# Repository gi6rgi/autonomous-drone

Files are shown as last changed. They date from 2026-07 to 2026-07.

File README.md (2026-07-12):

# Follow-me дрон: 5" deadcat на SpeedyBee F405 V3 + Raspberry Pi 5

Дрон, следующий за объектом: ArduPilot держит машину в воздухе, Raspberry Pi 5
видит цель через камеру и шлёт полётному контроллеру команды скорости по MAVLink
(режим GUIDED).

```
frame/frame.py        параметрическая рама (build123d -> STL/STEP)
frame/export/         готовые файлы: STL на печать, STEP для FreeCAD
software/follow/      код follow-me для Pi
software/tools/       утилиты: маркер, тест камеры, тест связи
```

---

## 1. Железо

### Что уже есть
SpeedyBee F405 V3 BLS 50A (FC+ESC), 6S 4000 mAh, моторы RETEK LN2207
(**используйте версию 1960 KV**, на первые полёты `MOT_SPIN_MAX` ~0.85),
винты 5.1x3.7x3, GPS Neo-M8M, Pi 5 + Arducam IMX219 175°, XT60, smoke stopper.

### Докупить обязательно
| Что | Зачем |
|---|---|
| Приёмник + пульт (ELRS 2.4G) | ручное управление и аварийный перехват. **Без RC не летать.** |
| BEC 5V/5A с входом 2–8S (до 35 В) | питание Pi 5. **MINI560 обычно до 20 В — на 6S сгорит, проверьте маркировку** |
| Крепёж: M3x12 (8 шт, армы) + гайки с нейлоном, стойки M3x30 (4) + M3x8 (8), M2.5x8 + стойки (Pi), M2x6 (камера), M3x8 (кронштейн/мачта) | сборка |
| Ремешок АКБ 20 мм, пенка под АКБ, стяжки | |
| Если на плате GPS нет компаса (чип QMC5883) | модуль GPS+компас — Loiter будет заметно стабильнее |

### Схема соединений
```
6S XT60 ─┬─ ESC (пады +/- , конденсатор Low-ESR прямо на пады!)
         └─ BEC 5V/5A ── Pi 5 (пины 5V: GPIO-пин 2/4 и GND 6)

FC UART (свободный, напр. T4/R4) ── Pi 5 UART: GPIO14 TXD -> RX FC,
                                    GPIO15 RXD <- TX FC, GND общий
GPS: TX/RX -> UART GPS-пады FC, SDA/SCL (компас) -> I2C пады FC
Камера IMX219 -> CSI-шлейф Pi 5 (нужен шлейф 22pin mini -> 15pin, если не в комплекте)
Приёмник ELRS -> UART2 FC (обычно пады T2/R2 + 4.5V)
```
Логика UART у FC и Pi — 3.3 В, соединяются напрямую. TX всегда крест-накрест с RX.

---

## 2. Рама

### Генерация
```bash
.venv/bin/python frame/frame.py     # -> frame/export/*.stl, *.step, assembly.step
```
Все размеры — параметры в начале `frame/frame.py` (база, толщина арма, наклон
камеры и т.д.). Поменяли — перезапустили — получили новые файлы. STEP открывается
во FreeCAD для доработки, `assembly.step` — вся рама в сборе для проверки.

### Детали и печать
| Деталь | Кол-во | Ориентация | Настройки |
|---|---|---|---|
| `arm.stl` | 4 | плашмя | PETG/ABS, **6+ периметров, заполнение 50% gyroid**, 100% для первых 2 мм |
| `bottom_plate.stl` | 1 | плашмя | 5 периметров, 40% |
| `top_plate.stl` | 1 | плашмя | 4 периметра, 30% |
| `camera_bracket.stl`, `gps_mast.stl` | 1+1 | базой вниз | обычные |

PLA не использовать (плывёт от нагрева моторов). Армы — расходник: печатайте
сразу 6 штук. Если MVP полетит стабильно — плиты и армы стоит перевести на
карбон, печатными оставить кронштейны.

### Сборка
1. Хвостовики армов вставляются в карманы снизу нижней плиты, M3x12 сверху,
   гайки с нейлоном снизу.
2. Моторы — на площадки армов (M3 из комплекта моторов), провода вдоль арма
   стяжками.
3. Стек на нижнюю плиту (30.5x30.5, люверсы), стрелка FC — вперёд (в нос).
4. Стойки M3x30 -> верхняя плита -> Pi 5 на стойках M2.5, камера в кронштейн
   на носу (наклон 10° вниз уже в детали), GPS на мачту на корме.
5. АКБ снизу на ремешке через прорези, пенка между АКБ и гайками армов.
   Двигайте АКБ вперёд/назад до баланса: центр тяжести — на оси стека.

---

## 3. Прошивка FC (ArduPilot)

1. Скачайте ArduCopter для таргета **SpeedyBeeF405v3** с firmware.ardupilot.org.
2. Первая прошивка — через DFU (зажать boot-кнопку, USB): STM32CubeProgrammer
   или Mission Planner -> Load custom firmware (`*_with_bl.hex`).
3. В Mission Planner: FRAME_CLASS=1 (Quad), FRAME_TYPE=1 (X). Deadcat-геометрию
   ArduPilot считает обычным X — для наших углов это ок.
4. Калибровки: акселерометр, компас, радио, ESC (BLHeli_S — протокол DShot300:
   `MOT_PWM_TYPE=4`).
5. Ключевые параметры:
```
SERIALx_PROTOCOL = 2      # MAVLink2 на UART, куда подключён Pi
SERIALx_BAUD     = 921    # 921600
MOT_PWM_TYPE     = 4      # DShot300
MOT_SPIN_MAX     = 0.85   # бережём моторы/ESC на 6S первое время
BATT_MONITOR     = 4      # ток+напряжение со стека
FS_THR_ENABLE    = 1      # потеря RC -> RTL
BATT_FS_LOW_ACT  = 2      # низкая батарея -> RTL
BATT_LOW_VOLT    = 21.6   # 3.6 В/банка
GUID_TIMEOUT     = 3      # нет команд от Pi 3 с в GUIDED -> зависание
```
6. Режимы на тумблеры: `Stabilize | AltHold | Loiter` + отдельный тумблер
   `RTL` и **GUIDED** (появится после настройки; GUIDED = «управляет Pi»).
7. Motor Test (без винтов!): порядок и направление по схеме ArduPilot X.

---

## 4. Raspberry Pi 5

```bash
# Raspberry Pi OS Bookworm 64-bit
sudo apt update && sudo apt install -y python3-picamera2 python3-opencv python3-pip
cd software && pip install -r requirements.txt --break-system-packages

# UART для FC: в /boot/firmware/config.txt добавить
#   enable_uart=1
#   dtparam=uart0=on
# и отключить консоль на serial: sudo raspi-config -> Interface -> Serial Port
#   (login shell: No, hardware: Yes). Порт: /dev/ttyAMA0 (GPIO14/15).
```

Камеру проверить: `rpicam-hello -t 5000` (для IMX219 обычно работает из коробки).

---

## 5. Проверка софта по шагам (до полёта)

```bash
cd software
python tools/generate_aruco.py            # напечатать маркер ~30 см, размер в config.yaml
python tools/test_camera.py               # кадр с детекцией -> frame.jpg
python tools/test_link.py                 # heartbeat, режим, батарея, GPS
python -m follow.main --dry-run           # весь конвейер без отправки команд
```

Опционально, без дрона — SITL на ПК (симулятор ArduPilot):
```bash
# https://ardupilot.org/dev/docs/sitl-simulator-software-in-the-loop.html
sim_vehicle.py -v ArduCopter --out=udp:127.0.0.1:14550
# в config.yaml: connection: udp:127.0.0.1:14550, camera.backend: opencv
# маркер показывайте в веб-камеру
```

---

## 6. Полётная программа (по порядку, не перескакивать)

1. **Стенд**: первое включение только через smoke stopper. Без винтов.
2. **Полёт 1–2**: Stabilize/AltHold, триммирование, затем AUTOTUNE (с этой
   массой стоковые PID будут вялыми).
3. **Полёт 3**: Loiter — дрон должен неподвижно стоять в точке. Пока Loiter
   не идеален, follow-me не включать.
4. **Полёт 4**: Pi запущен (`python -m follow.main`), маркер стоит на земле.
   Взлёт в Loiter, повернуть дрон камерой на маркер, тумблер -> **GUIDED**.
   Дрон должен довернуться на маркер и подойти на 4 м. Рука на тумблере:
   что-то не так -> LOITER.
5. Маркер в руках, медленная ходьба. Потом поднимать скорости в config.yaml.

**Безопасность**: открытое поле, без людей в радиусе 30 м; цель потеряна ->
Pi сам зависает через 0.5 с и уходит в LOITER через 5 с; батарея < 21 В ->
LOITER; RC-тумблер всегда главнее Pi.

## 7. Что дальше (после MVP)
- Fisheye-калибровка камеры (cv2.fisheye) — точные углы/дистанция по всему кадру.
- Трекинг человека: YOLOv8n (640x384, ~5–10 FPS на Pi 5) вместо ArUco,
  файл `follow/tracker.py` — добавить класс по образцу.
- Удержание высоты по цели (vz), follow сбоку/сзади, гео-забор в `safety.py`.

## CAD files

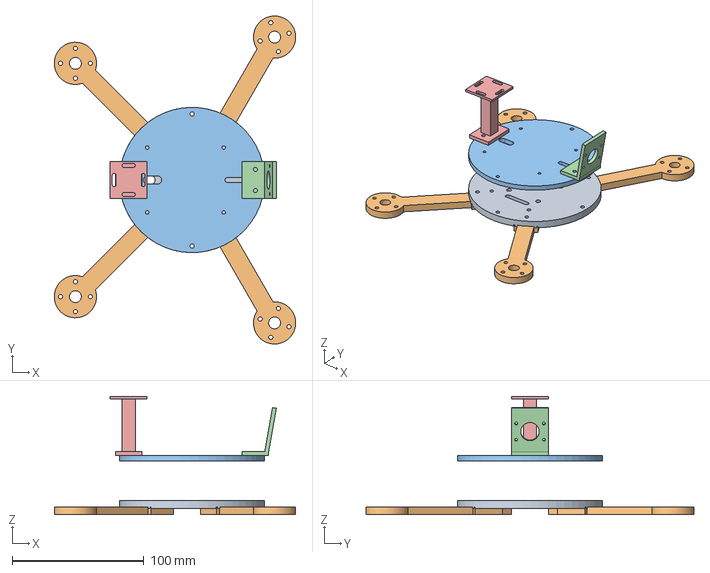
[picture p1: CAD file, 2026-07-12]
frame/export/assembly.step
182.8 x 248.5 x 89.7 mm

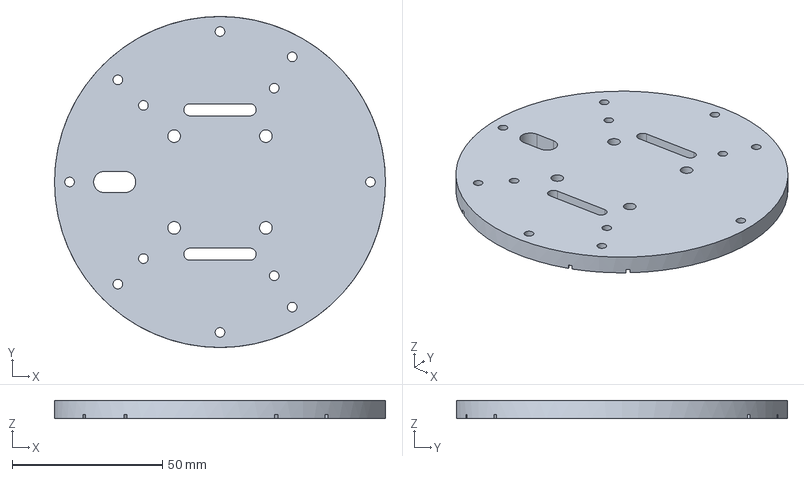
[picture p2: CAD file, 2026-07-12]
frame/export/bottom_plate.step
110.0 x 110.0 x 6.00 mm

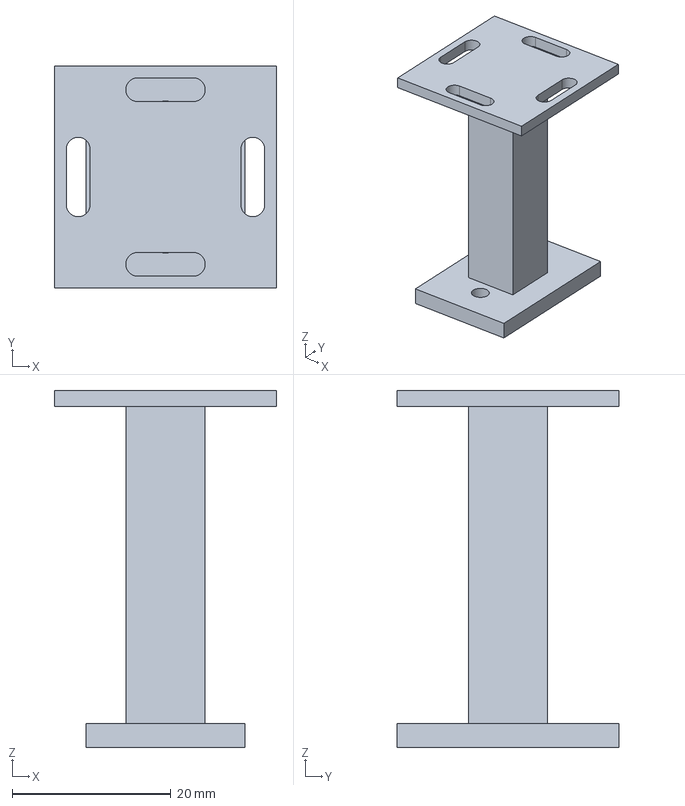
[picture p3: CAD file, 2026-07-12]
frame/export/gps_mast.step
28.0 x 28.0 x 45.0 mm

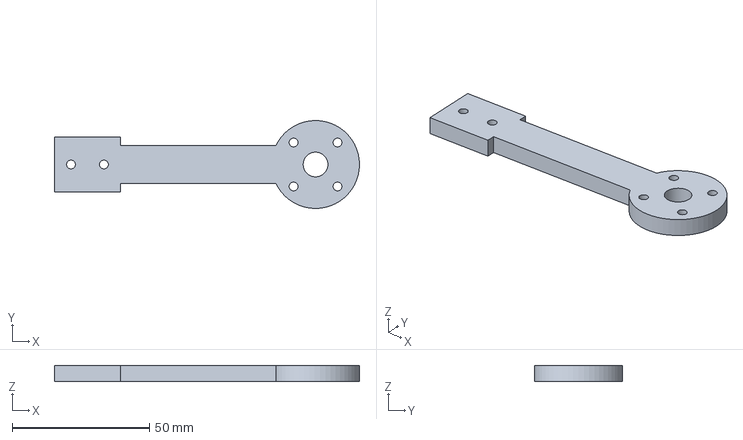
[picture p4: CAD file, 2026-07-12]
frame/export/arm.step
111.0 x 32.0 x 6.00 mm

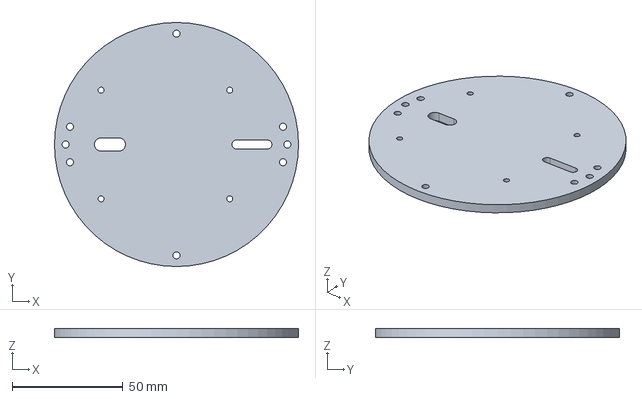
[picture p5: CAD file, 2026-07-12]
frame/export/top_plate.step
110.0 x 110.0 x 4.00 mm

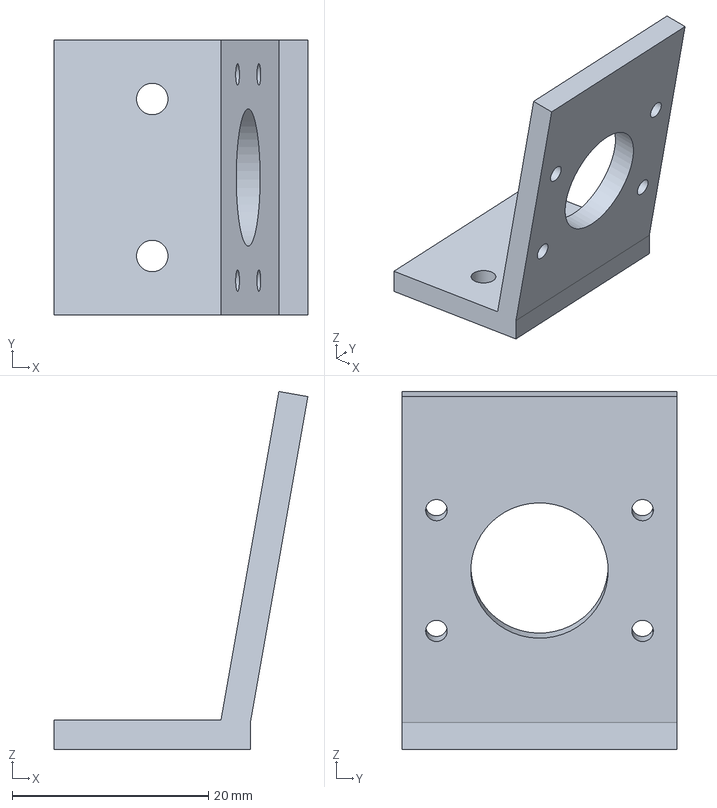
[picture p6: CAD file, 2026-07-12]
frame/export/camera_bracket.step
25.9 x 28.0 x 36.5 mm

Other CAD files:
frame/export/arm.stl
frame/export/assembly.FCStd
frame/export/bottom_plate.stl
frame/export/camera_bracket.stl
frame/export/gps_mast.stl
frame/export/top_plate.stl

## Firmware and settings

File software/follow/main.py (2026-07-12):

"""Главный цикл follow-me.

Запуск на Pi:      python -m follow.main --config config.yaml
Отладка без FC:    python -m follow.main --config config.yaml --dry-run

Логика: команды скорости отправляются ТОЛЬКО когда FC armed и в GUIDED.
Во всех остальных режимах программа лишь наблюдает и печатает телеметрию —
можно безопасно держать её запущенной с момента включения.
"""
from __future__ import annotations

import argparse
import time

import yaml

from .camera import Camera
from .controller import FollowController
from .safety import Safety, TRACK, HOVER, LOITER
from .tracker import make_tracker


def main():
    ap = argparse.ArgumentParser()
    ap.add_argument("--config", default="config.yaml")
    ap.add_argument("--dry-run", action="store_true",
                    help="без MAVLink: печатать команды вместо отправки")
    args = ap.parse_args()

    with open(args.config) as f:
        cfg = yaml.safe_load(f)

    camera = Camera(cfg["camera"])
    tracker = make_tracker(cfg["tracker"])
    controller = FollowController(cfg["follow"], cfg["camera"], cfg["tracker"])
    safety = Safety(cfg["safety"])

    link = None
    if not args.dry_run:
        from .mavlink_link import MavLink
        link = MavLink(cfg["mavlink"]["connection"], cfg["mavlink"]["baud"])
        link.wait_heartbeat()

    period = 1.0 / float(cfg["camera"]["fps"])
    last_log = 0.0
    loiter_sent = False

    try:
        while True:
            t0 = time.monotonic()
            frame = camera.read()
            if frame is None:
                continue
            target = tracker.update(frame)

            if link:
                link.pump()
            voltage = link.voltage if link else None
            engaged = bool(link and link.armed and link.flightmode == "GUIDED")
            act = safety.action(target is not None, voltage)

            vx = yaw = 0.0
            if act == TRACK and target is not None:
                vx, yaw = controller.update(target)
                vx, _, _ = safety.clamp(vx, 0, 0)

            if engaged:
                if act == LOITER:
                    if not loiter_sent:
                        link.set_mode("LOITER")
                        loiter_sent = True
                else:
                    loiter_sent = False
                    if act == TRACK and target is not None:
                        link.send_body_velocity(vx, 0, 0, yaw)
                    else:  # HOVER или цель ещё не появлялась
                        link.stop()
            elif args.dry_run and target is not None:
                pass  # команды считаются, печатаются ниже

            if t0 - last_log > 1.0:
                last_log = t0
                dist = f"{controller.distance_m(target):4.1f}м" if target else " -- "
                mode = link.flightmode if link else "DRY"
                print(f"[{mode}{' ARM' if link and link.armed else ''}] "
                      f"цель={'да' if target else 'НЕТ'} d={dist} "
                      f"vx={vx:+.2f} yaw={yaw:+5.1f} "
                      f"batt={voltage or 0:.1f}V act={act}")

            dt = time.monotonic() - t0
            if dt < period:
                time.sleep(period - dt)
    except KeyboardInterrupt:
        print("\nОстановка.")
    finally:
        if link and link.armed and link.flightmode == "GUIDED":
            link.stop()
        camera.close()


if __name__ == "__main__":
    main()

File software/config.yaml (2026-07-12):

mavlink:
  # На Pi 5 (UART GPIO14/15): /dev/ttyAMA0
  # Для отладки с SITL:       udp:127.0.0.1:14550
  connection: /dev/ttyAMA0
  baud: 921600

camera:
  backend: picamera2      # picamera2 | opencv (веб-камера для отладки на ПК)
  device: 0               # индекс камеры для opencv-бэкенда
  width: 1280
  height: 720
  fps: 30
  hflip: false
  vflip: false
  # Фокусное в пикселях по горизонтали. Для 175° линзы это ГРУБАЯ оценка —
  # для точной дистанции откалибруйте камеру (fisheye-модель OpenCV).
  fx_px: 550

tracker:
  mode: aruco             # aruco (рекомендуется для старта) | csrt
  aruco_dict: DICT_5X5_50
  aruco_id: 7
  marker_size_m: 0.30     # сторона напечатанного маркера, метры

follow:
  target_distance_m: 4.0  # держать такую дистанцию до цели
  max_forward_ms: 1.5     # ограничение скорости вперёд/назад, м/с
  max_yaw_rate_dps: 45    # ограничение скорости рыскания, град/с
  kp_yaw: 60.0            # град/с на единицу нормированной ошибки по X (-1..1)
  kp_dist: 0.6            # м/с на метр ошибки дистанции
  deadband_px: 30         # мёртвая зона по центру кадра

safety:
  target_lost_hover_s: 0.5   # цель потеряна дольше -> зависнуть (нулевые скорости)
  target_lost_loiter_s: 5.0  # цель потеряна дольше -> переключить FC в LOITER
  min_battery_v: 21.0        # 6S: 3.5 В/банка. Ниже -> LOITER и предупреждение
  max_speed_ms: 2.0          # абсолютный потолок любой команды скорости

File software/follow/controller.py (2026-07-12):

"""Ошибка цели в кадре -> команды скорости.

MVP-логика (высоту держит сам FC по баро):
  - цель левее/правее центра кадра -> yaw_rate, чтобы держать её по центру;
  - видимый размер цели -> оценка дистанции -> vx, чтобы держать дистанцию.

Внимание: 175° линза сильно искажает картинку. Пока цель около центра
кадра, линейное приближение работает; для точности нужна fisheye-калибровка
(tools/, см. README).
"""
from __future__ import annotations

from .tracker import Target


def _clamp(v: float, lim: float) -> float:
    return max(-lim, min(lim, v))


class FollowController:
    def __init__(self, follow_cfg: dict, camera_cfg: dict, tracker_cfg: dict):
        self.kp_yaw = float(follow_cfg["kp_yaw"])
        self.kp_dist = float(follow_cfg["kp_dist"])
        self.max_vx = float(follow_cfg["max_forward_ms"])
        self.max_yaw = float(follow_cfg["max_yaw_rate_dps"])
        self.deadband_px = float(follow_cfg["deadband_px"])
        self.target_dist = float(follow_cfg["target_distance_m"])
        self.frame_w = float(camera_cfg["width"])
        self.fx_px = float(camera_cfg["fx_px"])
        self.marker_size_m = float(tracker_cfg.get("marker_size_m", 0.3))

    def distance_m(self, target: Target) -> float:
        """Пинхол-оценка: d = S_реальный * fx / S_пиксельный."""
        return self.marker_size_m * self.fx_px / max(target.size_px, 1.0)

    def update(self, target: Target) -> tuple[float, float]:
        """-> (vx м/с вперёд, yaw_rate град/с, + вправо)."""
        err_px = target.cx - self.frame_w / 2
        if abs(err_px) < self.deadband_px:
            err_px = 0.0
        yaw_rate = _clamp(self.kp_yaw * err_px / (self.frame_w / 2), self.max_yaw)

        dist_err = self.distance_m(target) - self.target_dist
        vx = _clamp(self.kp_dist * dist_err, self.max_vx)
        return vx, yaw_rate

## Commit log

2026-07-12 Follow-me drone: parametric deadcat frame (build123d) + Pi companion software
    - frame/: параметрическая рама под 5.1" винты, SpeedyBee 30.5x30.5, Pi 5, IMX219, GPS-мачта (STL/STEP в frame/export)
    - software/follow/: камера, ArUco/CSRT трекер, контроллер, MAVLink GUIDED-мост, предохранители
    - software/tools/: генератор маркера, тесты камеры и связи
    - README: BOM, проводка, параметры ArduPilot, полётная программа
    [arm.step, arm.stl, assembly.step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]
2026-07-12 add assembled frame in FCStd format
    [assembly.FCStd]
